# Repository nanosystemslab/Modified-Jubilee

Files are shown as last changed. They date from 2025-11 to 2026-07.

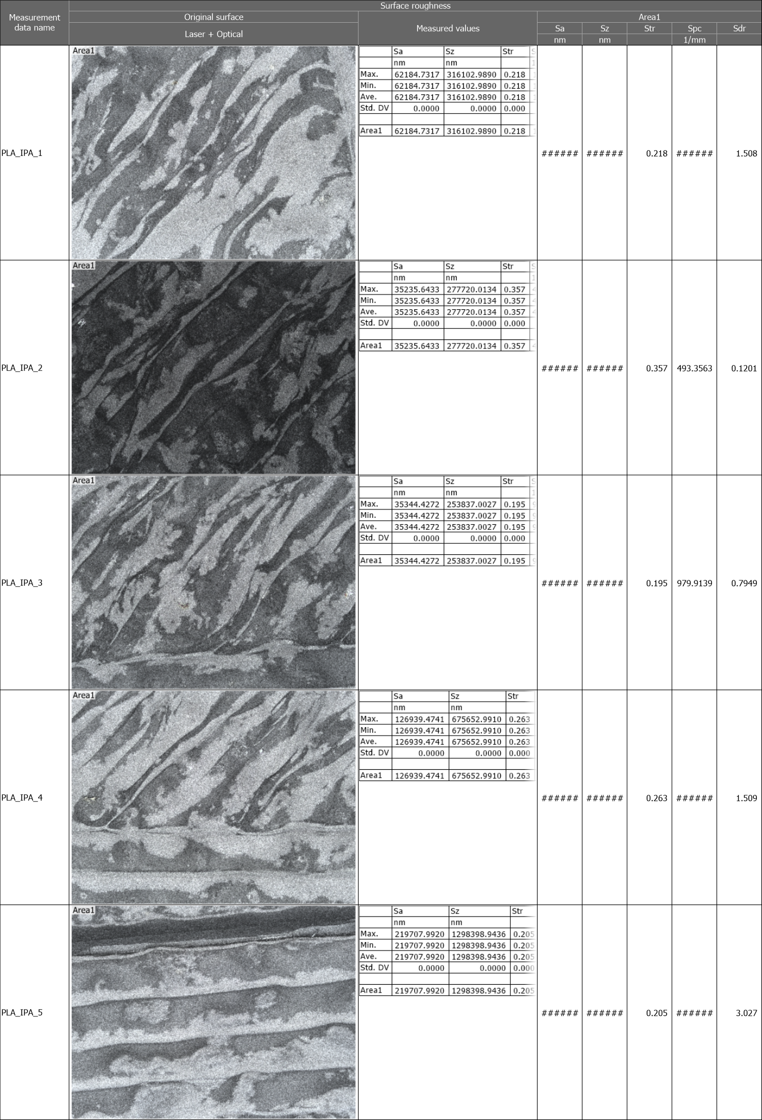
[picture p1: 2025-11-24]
degradation_testing/keyence_analysis/PLA_IPA_Results_Surface roughness.png

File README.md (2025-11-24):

# Modified Jubilee  
### Master’s Thesis Design Files & Documentation  

---

## Overview

This repository contains all design files, mechanical models, firmware, scripts, and supporting documentation used in the development of my Master’s thesis:

**“DESIGN, MODIFICATION, AND EVALUATION OF THE JUBILEE  
OPEN-SOURCE MOTION PLATFORM FOR AUTOMATED DIP COATING”**

This repository exists to support replication, modification, and extension of the system in alignment with open-source hardware principles.

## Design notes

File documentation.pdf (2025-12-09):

# Table of Contents

Purchasing Components:
- Purchase Order 1 (10/8/2024):
- Total procurement time: 3 Weeks
- Aluminum 6061 Plates
■ Procurement Time: 2.5 weeks
■ Manufacturing Time: 3 weeks
- Better to spend the extra money to get the plates machined from an external supplier to accelerate the assembly process
- Filastruder:
■ Missing tool changer stepper motor and its corresponding wires
- Tried to get a replacement part, but Filastruder only offers replacements within 2 week of delivery
- Didn’t notice missing component whilst confirming the contents of all the packages
- Realized 6 weeks post delivery once assembling the tool changer component

Resin Printing:
- General Settings:
- Printer: Formlabs 3/3+
- Material(s): Tough 1500, Grey V4
- Print Orientation: 45º angle
- Layer Thickness: 0.1mm
- Removed generated supports from the inside of screw holes
- Post Processing
- Component Cleaning:
■ First manual IPA wash for 15-30 seconds
■ Second manual IPA wash for 15-30 seconds ■ Automatic IPA wash for 15 minutes
- Material: Tough 1500
■ Cure Settings:
- Temperature: 70º C
- Time: 60 minutes
- Material: Grey Resin V4
■ Cure Settings:
- Temperature: 60º C
- Time: 30 minutes
- Problems:
- Material: Tough 1500
■ Print failure while printing back and front feet
- Both prints failed the first time and succeeded the second time with no changes to the form file
- Reason for failure: Unknown. Should compare the slicer settings of the nslab desktop to my laptop settings
- Heat Creep
■ Research heat creep with formlabs or try different resin type
- Possible debris inside of the resin tank
■ Clean thoroughly or replace
- Dirty/Obstructed UV light
■ Clean thoroughly or replace
- Material: Grey Resin V4
■ Heat inserts don’t stay inside of components
■ Brittle material, lead to some components snapping/breaking

Aluminum Top and Bottom Plates:
- General Information:
- Purchased 2 Aluminum Plates 6061: T651, 24 in Overall Lg, 24 in Overall Wd, 0.25 in Thick, Mill, +/-0.012 in
■ Procurement time: 2.5 weeks
- Had the machine shop cut the Aluminum Plates with the water jet
■ Sent .stl cad files
■ Procurement time: 2.5 weeks
- Problems:
- Aluminum Plates after receiving them from the machine shop: ■ Not all holes were cut all the way with the water jet
- Was able to tap out some of the holes that were mostly cut with hammer
- Rest of the holes had to be drilled out
- 1st Attempt: Took it to FabLab, but the drill press was unable to cut through the aluminum likely due to a lack of speed
- 2nd Attempt: Took it to the machine shop to use their drill press, but had issues with alignment and clamping due to the size of the plates
- 3rd Attempt: Clamped the aluminum plates to a table and hand drilled the holes out with the corresponding drill bit size
■ Finished holes are not perfectly aligned with the corresponding components
■ No finish on the aluminum plates
- Took the deburring tool to smooth out the rough edges on the aluminum plates
■ Minor issue: plates are dirty
- Can clean with IPA or acetone
- Top aluminum plate changed the overall height of the Jubilee. The toolhead can crash into the back Z stopper.
■ Solution: Change the home all function to home x first and y second:
1. Open the homex.g file and comment out the following lines:

if !move.axes[1].homed
M291 R"Cannot Home X" P"Y axis must be homed before x to prevent damage to tool. Press OK to home Y or Cancel to abort" S3
M98 P"homey.g"

2. Then open the homeall.g file and switch the order of the homey.g and homex.g. Should look like this:

; Home y, x, z, and Toolchanger Lock axes

M98 P"homeu.g" ; X and Z require U to be homed first in case a tool is currently active M98 P"homex.g"
M98 P"homey.g"
M98 P"homez.g"

CAD Modeling:
- Heat Inserts:
- Create a countersink hole that extends through the entire component, allowing the heat insert to be threaded into the resin using a screw and washer
■ The following measurements are inner and outer diameters (ID and OD) depending on the insert size
- M3:
- ID: 5.4mm, OD: 6.4mm
- M4:
- ID: 5.9mm, OD: 6.9mm
- For parts that can’t have through holes, press fit inserts into component(s) using a vise
- Back/Top Aluminum Plates:
- Design Process:
■ Create a sketch to represent the horizontal aluminum extrusions or “old frame” (top and bottom) and include all of the vertical aluminum extrusions as well as the PLA components that rest on each frame.
- To create sketches of the solid parts, create a plane on the surface of the face being drawn and offset any planes if necessary.
- If a plane was offset to copy a certain detail of the part, after the detail is drawn switch the sketch plane back to its original plane.
■ Create a sketch of the “new frame” that follows the dimensions of the old frame
- Both top and bottom frames widths were extended by ½” (¼” on each side) to allow for side panels to sit flush with the frames
- After the new frame is sketched and extruded, use the previous sketches of the vertical aluminum extrusions and PLA components to create corresponding holes for each component
■ Ensure each hole is a through hole and the correct diameter
■ Determine which of the holes need to be threaded and which don’t
- All holes that align with the vertical aluminum extrusions do not need threads as they will thread directly into the extrusion ■ Add any adjustments necessary for the new frame

- For the top frame, add a slit at the front of the frame to allow for the addition of new tools such as the Opentron Pipette
- Divide the slit into thirds to provide more rigidity to the structure while maintaining mountability
- Behind the slit add through holes (Number of holes and spacing is up to you) for tools that need to be mounted from the bottom
- For the bottom frame, redesign larger feet to cover more surface area and provide more support to compensate for the increased weight
■ Spacers will need to be added to the motors to compensate for the loss in height with the new assembly
- Calculate the difference in height between the original assembly and new assembly by subtracting the thickness of the horizontal aluminum extrusion (20mm) by the thickness of the top plate (¼” = 6.25 mm)
- 20mm − 6. 25mm = 13. 75mm ≈ 14mm spacers
- The height of the feet will also need to increased by 14mm to ensure that the motors are suspended above the surface the Jubilee is on
■ Lastly import other solid parts to ensure all holes are properly aligned with the frames
- Panels:
- Design Modifications:
■ Back Panel (Electronics Panel):
- Remove 13.65mm from the top and bottom of the panel for it to fit within the dimensions of the modified Jubilee
- Disregard screw holes removed as those can’t be used anyways
- Will be mounted using the holes on the side of the panel ■ Can screw into T-slots mounted to the vertical extrusions
■ Side Panels:
- Remove 20mm from the top and bottom of both side panels (40mm total removed) for it to fit within the dimensions of the modified Jubilee
- Disregard screw holes removed as those can’t be used anyways
- Will be mounted using the holes on the side of the panel

■ Can screw into T-slots mounted to the vertical extrusions
- Automation Deck:
- General Information:
■ Purpose: Modular frame to hold different beakers, tip racks, sample holders, etc.
■ Material: PLA
■ Size: 305mm x 305mm
- Design Process:
■ Create a sketch of the build plate using the original magnetic plate as a layout for the automation deck design to get accurate dimensions
■ Extrude the sketch 6.35 mm (¼ in) to create the automation deck part
■ Sketch 4 equal squares (137.5 mm x 137.5 mm) on the automation deck with 10 mm of spacing between each square
■ Design dovetail connections on the edges of each square to create modular insertions
■ Extrude remove the 4 squares + dovetail connections for the automation deck holders to be inserted
■ Divide design into 4 parts with connectors to fit inside of Bambu X1E build volume
- Automation Deck Holders:
- Design process:
■ Create a sketch using one of the modular holes from the automation deck as a layout to get accurate dimensions
■ Offset the sketch inwards by 0.1 mm
- This is to ensure that the holder can slide into place without force, but still provide a snug fit
■ Extrude the sketch 6.35 mm (¼ in) to match the height of the automation deck
■ Sketch the dimensions of the object (tip rack, vial holder, wellplate, beaker, etc.) on the center surface of the holder
■ Extrude remove the sketch 4.35 mm
- Leave 2 mm of space between your object and the magnetic build plate to keep the two from making direct contact
- Automation Deck Holder - Sample Holder:
- Dry Sample Holder Design Process:
■ Sketch a rectangle that measures 85.5 mm x 127.75 mm ■ Extrude the rectangle 60 mm

■ Create the sample slots:
- Create a construction line 22.5 mm away one of the 127.75 mm sides of the rectangular prism
- Sketch a center point rectangle on the construction line that measures 27 mm x 3 mm
- Create a 2 mm outward offset on this rectangle
- Dimension the 2 rectangles to be 5 mm from one of the 85.5 mm sides of the prism
- Create a linear pattern of the rectangles along the surface of the prism
- This patter should be 10x in the vertical direction and 2x in the horizontal direction
- Spacing between the patterns should be 12.306 mm
■ Extrude remove the slots 53.65 mm
■ Add 5 mm fillets to the corners of the base
■ On the surfaces of the front slots, sketch a center point rectangle that measures 53.65 mm x 23 mm
■ Extrude remove all the way through the object
■ Finally, face blend the base of each slot with a radius of 2.5 mm
- Wet Sample Holder Design Process
■ Design process is the exact same as the dry sample holder, but the dimensions are slightly larger
- These slots will be slightly bigger to allow for more space between the sample and the holder
■ Sketch a rectangle that measures 85.5 mm x 127.75 mm
■ Extrude the rectangle 60 mm
■ Create the sample slots:
- Create a construction line 22.5 mm away one of the 127.75 mm sides of the rectangular prism
- Sketch a center point rectangle on the construction line that measures 29 mm x 5 mm
- Create a 2 mm outward offset on this rectangle
- Dimension the 2 rectangles to be 4 mm from one of the 85.5 mm sides of the prism
- Create a linear pattern of the rectangles along the surface of the prism
- This patter should be 10x in the vertical direction and 2x in the horizontal direction
- Spacing between the patterns should be 12.306 mm
■ Extrude remove the slots 53.65 mm

■ Add 5 mm fillets to the corners of the base
■ On the surfaces of the front slots, sketch a center point rectangle that measures 53.65 mm x 20 mm
■ Extrude remove all the way through the object
■ Finally, face blend the base of each slot with a radius of 1.65 mm
- Vacuum Tool:
- Design Process:
■ Start by sketching a circle with a 14 mm diameter
- This will be the part that contacts the sample
■ Extrude the circle 5 mm
■ On the surface of the cylinder, sketch 2 circles from the centerpoint. ID: 5.12 mm, OD: 7.12 mm
■ Then sketch a path perpendicular to the surface of the cylinder with a height of 20 mm and a length of 25 mm
■ Sweep the face of the circles sketched on the surface of the cylinder using the perpendicular line as the path of the sweep
■ Add a 5 mm radius fillet to the circle at the base of the sweep
- This should create a sturdy connection between the original cylinder and sweep
■ On the bottom surface of the cylinder, sketch a 12 mm diameter circle ■ Extrude remove the 12 mm circle by 5 mm
■ Fillet the inner base of the sweep 5 mm
■ On the bottom surface of the cylinder, create a vacuum chuck design.
- Sketch a 12 mm circle
- Offset sketch a circle from the 12 mm circle by 2 mm
- Offset sketch a circle from the 10 mm circle by 1.2 mm
- Repeat this pattern of offsets (offset by 2 mm, then 1.2 mm) until you can't anymore.
- Sketch 2 perpendicular rectangles along the horizontal and vertical centers of the base of the cylinder
- Extrude remove the 1.2 mm spacings 5 mm to finish chuck design ■ At the opposite end of the model (opening of the sweep), create a sketch perpendicular to the drawing to make the hose barb.
- Sketch 5 mm up from the center of the sweep
- Sketch a 5 mm line away from the surface
- Sketch a 1.3 mm line down
- Sketch a 2 mm line away from the surface
- Sketch a 0.8 mm line up and then a diagonal line 60 degrees from the vertical line.

- The length of the diagonal line should be 1.6 mm
- Copy and paste the barb 7 time to create 8 total barbs
- Close the drawing then revolve the sketch
- Fillet the base of the sweep and the hose barb 2 mm
■ Offset a plane from the center of the 25 mm length of the sweep
■ Create a sketch on that plane and make a rectangle that measures 33.45 mm x 10.45 mm
- Add 2 points 2.725 mm away from the center of the short walls ■ Extrude the sketch 7 mm to connect it to the vacuum tool
■ Add 2 mm fillets between the extruded rectangle and the vacuum tool ■ Finally, create 3.4 mm through holes using the points created in the rectangle sketch

Jubilee Assembly:
- Problems:
- L shaped vertical aluminum extrusions don’t have long enough threads. ■ Solution:
- Buy shorter M5 screws to fit within the thread length
- Holes on the aluminum bottom plates aren’t perfectly aligned with the corresponding components
■ Solution:
- Redrill the holes (Only works for the components that require through holes and not threaded holes)
- Tool wires are heavy and are not well suited for traveling over the top of the Jubilee
■ Solution:
- Reroute the wires

Degradation Testing:
- Keyence Analysis:
- General:
■ 5x Lens
■ Stitched 5 images of the center of the dogbone
- Testing Procedure:
1. Specimen fabrication
a. Design and 3D print 40 ASTM D638 Type V dogbone specimens, consisting of 20 PLA and 20 Grey Resin V4 samples.
2. Solvent exposure
a. Submerge five dogbones of each material in water, isopropyl alcohol (IPA), and acetone for 24 hours.
b. Retain five additional dogbones of each material as unexposed control specimens.
3. Post-immersion inspection
a. After submersion, visually inspect each specimen using a Keyence confocal laser scanning microscope.
b. Acquire and stitch approximately five image scans of the mid-gauge section for each dogbone.
4. Mechanical testing
a. Test every specimen using a Shimadzu tensile tester in accordance with ASTM D638 procedures.
b. Export the resulting force–displacement data as a .csv file.
5. Data analysis
a. From the recorded data, calculate tensile strength, tensile strain at break, and Young’s modulus for each specimen.
- Results:
- Water:
■ In comparison to the control samples for both PLA and Grey Resin V4, the dog bones submerged in water after visual inspection showed no significant differences in appearance.
- IPA:
■ In comparison to the control samples for Grey Resin V4, the dog bones submerged in IPA after visual inspection showed no significant differences in appearance.
■ In comparison to the control samples for PLA, the dog bones submerged in IPA after visual inspection showed extreme disfigurement.
- Acetone:

■ In comparison to the control samples for both PLA and Grey Resin V4, the dog bones submerged in acetone after visual inspection showed no significant differences in appearance.
- Tensile Testing (ASTM D638 Type V):
- General Information:
https://www.ssi.shimadzu.com/products/materials-testing/uni-ttm-system/tensile-test-methods-for-plastics-astm-d638/spec.html (https://www.ssi.shimadzu.com/products/materials-testing/uni-ttm-system/tensile-test-methods-for-plastics-astm-d638/spec.html)

https://www.astm.org/d0638-22.html

https://eddieliberato.github.io/blog/2020-05-14-dogbones/
■ Dogbone specimen dimensions (ASTM D638 Type V):
- Overall length: 63.5 mm
- Gauge length: 7.62 mm
- Width of narrow section (gauge width): 3.18 mm
- Length of narrow section: 9.53 mm
- Distance between grips (overall length of reduced section + grip sections): 25.4 mm
- Width of ends (grip section): 9.53 mm
- Thickness: 3.2 mm (nominal)
- Radius of fillet (transition between narrow and grip sections): 14 mm
■ PLA Print Settings:
- Printer: Bambu Lab P1S
- AMS Attachment
- Filament Type: White PLA Basic
- 0.4mm nozzle
- No supports
- 0.2mm layer height
- 6 perimeter layers (This is especially critical for parts that have heat-set inserts)
- 20% infill * printable in the provided orientations
- outer perimeter layer first
- uncheck "Detect Thin Walls" if your Slicer has this setting.
- Otherwise, small gaps will not be filled.
■ Grey Resin V4 Print Settings:
- Printer: Formlabs 3/3+
- Print Orientation: 45º angle
- Layer Thickness: 0.1mm
- Cure Settings:

- Temperature: 60º C
- Time: 30 minutes
- Data analysis script description:
1. Mount Google Drive and define the data folder.
a. Connects to Google Drive (drive.mount) and sets a folder path containing tensile-test CSV files.
2. Locate all CSV data files.
a. Scans the selected folder and lists every .csv file to be analyzed.
3. Define sample geometry (ASTM D638 Type V).
a. Sets:
i. Gauge length = 7.62 mm
ii. | Width = 3.18 mm
iii. | Thickness = 4 mm
iv. | Cross-sectional area A = width × thickness (mm²)
4. Loop through each CSV file.
a. For every sample:
i. Load the file as a DataFrame with columns Time (s), Force
| (N), and Stroke (mm).
ii. | Remove commas or stray characters and convert text to
| numeric values.
iii. | Drop any rows containing invalid or missing data.
5. Compute stress and strain.
a. Stress (MPa) = Force (N) ÷ Area (mm²)
b. Strain = Stroke (mm) ÷ Gauge length (mm)
6. Estimate Young’s modulus.
a. Select the linear elastic region where strain ≤ 0.002.
b. Perform a linear regression of stress vs. strain.
c. The slope of the fitted line gives Young’s modulus (MPa).
7. Determine tensile strength and elongation.
a. Tensile strength: maximum stress value.
b. Tensile strain: strain corresponding to that maximum stress.
8. Store all calculated results.
a. Saves the computed tensile strength, tensile strain, and Young’s modulus for each sample into a results list.
9. Create a summary table.
a. Converts results into a single DataFrame and adds an “Average” row showing mean values for all samples.
10. Display the summary.
a. Prints a formatted summary table listing all sample files with their corresponding calculated properties and overall averages.

11. Export results to Excel.
a. Writes the summary DataFrame to batch_summary.xlsx in the same Drive folder for record-keeping.
- Future Improvements
- Test multiple different resins ■ Issue:
- Grey Resin V4 is very brittle and not ideal for lots components ■ Solution:
- Test another Formlabs resin such as Tough 1500 which is more flexible than Grey
- Isolate dogbone samples after printing ■ Issue:
- Material properties of the samples will change depending on the environment it is left in causing variations in Tensile Data
■ Solution:
- Place dogbones in a dry box to prevent environmental effects

Vibration Testing:

### 1. Standalone Vibration Data Logger

a. Components:
i. Adafruit MPU-6050 6-DoF Accel and Gyro Sensor - STEMMA QT Qwii (https://www.adafruit.com/product/3886)
ii. | Raspberry Pi Pico WH - Pico Wireless with Headers Soldered (https://www.adafruit.com/product/5544)
iii. | Adafruit PCA9548 8-Channel STEMMA QT / Qwiic I2C Multiplexer -
| TCA9548A Compatible (https://www.adafruit.com/product/5626)
iv. | STEMMA QT / Qwiic JST SH 4-Pin Cable (https://www.adafruit.com/product/4399)
v. Bread Board
vi. | Jumper wires
vii. | 3D printed MPU-6050 holders
b. Testing locations:
i. Tool changer
ii. | Bed
iii. | Frame
Testing procedure:
1. Hardware setup
a. Connect the Raspberry Pi Pico WH and one Adafruit MPU-6050 accelerometer on a breadboard using jumper wires.
b. Connect the I²C multiplexer to the MPU-6050 via a JST 4-pin cable.
2. Sensor mounting
a. Mount the Raspberry Pi + MPU-6050 breadboard assembly onto the magnetic build plate.
b. Mount the other two MPU-6050 sensors to the tool head and the aluminum vertical extrusion, respectively.
3. Electrical connections
a. Connect all mounted MPU-6050 boards to the multiplexer using JST connector cables.
b. Power the Raspberry Pi Pico WH through the micro-USB connector attached to a computer.
4. Software setup
a. Upload the triple_accel.py data-acquisition script to the Raspberry Pi using Thonny.
b. Upload the X-, Y-, and Z-axis simulation scripts to VS Code on the host computer.
5. Data acquisition
a. Run the triple_accel.py script on the Raspberry Pi.
b. After the initial sensor calibration completes, start the corresponding axis simulation script in VS Code.
6. Test completion a. When the VS Code terminal indicates that the simulation has finished, stop the triple_accel.py script to end data collection.
7. Data handling and analysis
a. Download the generated .csv data file from the Raspberry Pi.
b. Process the file using the vibration-analysis Python script to generate FFT and time-domain plots.
8. Repetition
a. Repeat the complete procedure for each axis (X, Y, Z) on both the modified and original Jubilee platforms.

Data collection script description:
1. Pick an I²C bus that actually works.
a. Tries a few common Pico pin combos and selects the first config that returns any devices on a scan.
2. Probe what’s on the bus.
a. Scans for a PCA9548A I²C multiplexer and for any directly connected MPU6050 (0x68).
3. If a PCA is present, sanity-check its channels.
a. Selects channels (0–7), scans each for an MPU6050 at 0x68, records which channels really have sensors, then disables all channels.
4. Instantiate sensor objects.
a. Adds a direct MPU6050 if one is found on the main bus.
b. Adds PCA-routed MPU6050s for the channels that tested positive (e.g., Ch0, Ch1).
5. (Optional) Calibrate all sensors.
a. If enabled, asks you to leave the rig still, averages a bunch of samples per sensor, and sets offsets so X≈0 g, Y≈0 g, Z≈+1 g when level.
6. Let everything settle.
a. Waits a few seconds (warm-up), then repeatedly tests stability: collects short bursts from each sensor and checks that the standard deviation of X, Y, Z, and |accel| is below a small threshold. Retries up to a fixed limit.
7. Choose the run mode: live or log.
a. Live mode: continuously prints each sensor’s X, Y, Z, and acceleration magnitude at the target sample rate.
b. Logging mode: writes rows to a CSV file at the target sample rate for the specified duration (or until you stop it).
8. Sample loop (both modes).
a. On each tick: read all sensors, compute magnitude, mark any failed read as NaN, and keep time with millisecond ticks.
9. Progress feedback.

a. Once per second, prints a status line with elapsed time, total samples, and whether any read errors occurred.
10. Clean finish.
a. On duration end (or Ctrl+C), stops the loop; in logging mode it closes the file and reports how many samples and sensors were captured.
11. Core assumptions & constants baked in.
a. MPU6050 is at ±2 g scale (divides raw by 16384).
b. Default addresses: PCA = 0x70, MPU6050 = 0x68.
c. Defaults include sample rate (e.g., 500 Hz), settling window, stability threshold, and which PCA channels to try.

X-axis movement script description:
1. Initialize the controller.
a. The script starts by defining the Jubilee’s IP address and creating an HTTP session to communicate with the Duet 3 web control interface.
2. Set movement parameters and limits.
a. It defines safe X-axis limits (e.g., −3 mm to 303 mm) and a default travel speed (e.g., 3000 mm/min).
3. Send G-code commands through HTTP.
a. Commands like G1 X... F... are sent to the printer’s /rr_gcode endpoint to move the tool head, and responses are read back as JSON.
4. Check current position.
a. The code queries /rr_status to get the current X coordinate and uses it as the reference “starting position.”
5. Run a defined number of back-and-forth cycles (default = 3).
a. For each cycle:
i. Move the tool head to the minimum X position.
ii. | Wait until motion completes and optionally pause for a few seconds.
iii. | Move the tool head to the maximum X position.
iv. | Wait again and pause.
v. Log progress and repeat until all cycles are done.
6. Wait for motion to finish before continuing.
a. Uses M400 and periodic status checks to confirm the machine is idle before proceeding to the next move.
7. Pause at end points for sensor stability.
a. Short pauses (e.g., 5–10 s) give time for accelerometer data collection or vibration settling before direction changes.
8. Return to the starting position.
a. After completing all cycles, the script moves the X-axis back to the original position where the test began.

9. Handle errors gracefully.
a. If anything fails (connection loss, timeout, etc.), it logs the error and tries to return the tool head to the starting position.
10. Provide detailed logging output.
a. Throughout the run, timestamps and messages are written to the console describing every movement, pause, or error condition.

Y-axis movement script description:
1. Connect to the Jubilee printer.
a. The script begins by creating an HTTP connection to the Duet 3 controller using the printer’s IP address.
2. Define motion limits and speed.
a. Safe travel bounds for the Y-axis (e.g., −34 mm → 280 mm or 295 mm) and a default feed rate (≈ 3000 mm/min) are set.
3. Send motion commands via HTTP.
a. G-code commands such as G1 Y### F### are sent to the /rr_gcode endpoint to move the toolhead along the Y-axis.
4. Read current position.
a. The script queries /rr_status to determine the current Y coordinate, which is saved as the “starting position.”
5. Run a multi-cycle travel routine.
a. The head moves from minimum → maximum → minimum Y positions for a set number of cycles (default = 3).
6. Pause at each extreme.
a. After reaching each limit, the machine waits several seconds (e.g., 5–10 s) to allow for vibration settling or acceleration-sensor sampling.
7. Wait until motion completes.
a. The script issues an M400 command and repeatedly checks printer status to confirm the move has fully finished before continuing.
8. Repeat the pattern.
a. Each back-and-forth motion counts as one cycle; short pauses occur between cycles to ensure consistent timing.
9. Return to the start position.
a. Once all cycles finish, the head moves back to its original Y location and confirms completion.
10. Handle errors safely.
a. If communication or motion fails, the script logs the problem and attempts to return the toolhead to its starting point before exiting.
11. Log progress to the console.
a. Every major action—move, pause, completion, or error—is time-stamped and printed for test documentation.

Z-axis movement script description:
1. Connect to the Jubilee’s controller.
a. The script starts by creating an HTTP session to communicate with the Duet 3 web control interface using the Jubilee’s IP address.
2. Define safe motion parameters.
a. It sets a safe vertical travel range (e.g., 10 mm → 290 mm) and a conservative default speed (around 2000 mm/min) since the Z-axis moves the entire tool head assembly.
3. Send G-code commands over HTTP.
a. Commands such as G1 Z### F### are sent to move the tool head up or down, and /rr_gcode responses confirm successful communication.
4. Determine the starting Z position.
a. The script queries the printer’s /rr_status endpoint to read the current Z coordinate, storing it to return to later.
5. Run a three-cycle motion routine.
a. For each of the three cycles:
i. Move down to the minimum Z limit (closest to the bed, but safely above it).
ii. | Wait until motion finishes and pause for a few seconds.
iii. | Move up to the maximum Z limit (near the top of travel).
iv. | Wait again and pause.
v. Record progress and continue.
6. Confirm each motion is complete.
a. The script issues M400 (wait for moves to finish) and periodically checks machine status until it reports idle.
7. Include controlled pauses.
a. Short dwell times at each endpoint allow vibration damping or sensor data capture before the next move.
8. Repeat until all cycles finish.
a. Each up-and-down motion pair counts as one cycle; after three cycles the sequence stops.
9. Return to the starting height.
a. Once the final cycle is complete, the head moves back to its original Z position and confirms motion completion.
10. Handle errors gracefully.
a. If communication or motion fails, the script logs the issue and tries to safely return the tool head to its start position.
11. Provide continuous console feedback.

a. Every move, pause, and status check is timestamped and printed through the logger, giving a clear record of the full test.

Data analysis script description:
1. Configuration and Sensor Mapping:
a. Each script defines a fixed sampling rate of 100 Hz.
b. Accelerations are provided in units of g and converted to m/s² using a constant multiplier.
c. Displacement calculations convert meters to millimeters.
d. Sensor names are mapped to physical locations on the system:
i. MPU_Direct → bed plate
ii. | MPU_Ch0 → vertical extrusion
iii. | MPU_Ch1 → tool head
c. Each sensor location is assigned a distinct color for all plots.
d. The scripts specify:
i. Path to the folder containing CSV files
ii. Output directory for figures and summary spreadsheets
2. Input Data and Column Requirements:
a. All CSV files must contain consistently named columns for each sensor.
b. The FFT analysis script expects magnitude columns for each sensor, such as:
i. MPU_Direct_mag
ii. | MPU_Ch0_mag
iii. | MPU_Ch1_mag
c. The displacement analysis script expects x, y, and z acceleration component columns for each sensor.
d. The displacement script requires a timestamp column in seconds.
e. The scripts assume the sampling rate and do not estimate it from the data.
3. Frequency-Domain Analysis (FFT Script)
a. Each CSV file is processed sequentially.
b. For each sensor:
i. The acceleration magnitude is read from the corresponding column.
ii. | Values are converted from g to m/s².
iii. | The mean is removed to eliminate DC offset.
iv. | A Hanning window is applied to reduce spectral leakage.
v. A Fast Fourier Transform (FFT) is performed using a one-sided spectrum.
vi. | Frequency bins are generated based on the sampling rate and number of
| samples.
vii. | FFT magnitudes are normalized properly for comparison.
c. Peaks are automatically identified:
i. Frequencies below 1 Hz are ignored.

ii. | Peak detection uses a prominence threshold based on data amplitude.
iii. | The top three peaks are extracted, sorted, and reported.
d. FFT figures include:
i. Frequency range from 0 to 50 Hz
ii. | Clean spectrum lines for all sensors
iii. | Markers at each dominant peak
iv. | Sensor labels, legend, and grid lines
e. Each figure is saved as a PNG file with a filename indicating the source CSV.
f. Numerical results printed for each file include:
i. Sampling rate and Nyquist frequency
ii. | Frequency resolution
iii. | Three dominant vibration frequencies for each sensor
iv. | Corresponding magnitudes
4. FFT Summary Outputs for Multiple Files
a. When more than one CSV file is present, the script generates:
i. A summary comparison figure showing peak frequencies and magnitudes
| across all files and sensors
ii. | An Excel spreadsheet containing:
1. Peak frequencies and magnitudes for each file and sensor
2. Pivot tables comparing the dominant peak across all tests
5. Time-Domain Displacement Analysis (Displacement Script)
a. Each CSV file is processed sequentially using x, y, and z accelerations.
b. For each sensor and each axis:
i. Acceleration is converted from g to m/s².
ii. | The mean is removed.
iii. | A fourth-order Butterworth band-pass filter is applied:
1. Passband: 5–40 Hz
iv. The filtered acceleration is integrated numerically to obtain velocity.
v. Velocity is detrended to remove drift.
vi. | Velocity is integrated again to obtain displacement.
vii. | Displacement is detrended to remove offset and low-frequency drift.
c. The displacement magnitude is computed from the x, y, and z components and converted to millimeters.
d. For each sensor:
i. RMS displacement is calculated.
ii. Peak displacement and the time of occurrence are determined.
e. Each displacement-versus-time figure includes:
i. Traces for all sensors
ii. | RMS displacement in the legend
iii. | A marker and label at the maximum displacement point

iv. Axes labels, legend, and grid
f. Each figure is saved as a PNG file using the source CSV filename.
6. Displacement Summary Outputs for Multiple Files
a. When multiple CSV files are processed, the script generates:
i. A comparison plot showing RMS displacement for each sensor across all
| tests
ii. | A comparison plot showing peak displacement for each sensor across all
| tests
iii. | An Excel summary file containing:
1. RMS displacement for each file and sensor
2. Peak displacement for each file and sensor
3. Time of maximum displacement
4. Pivot tables for cross-file comparisons
7. Batch Processing and Running the Scripts
a. Both scripts automatically scan the data folder and process every CSV file found.
b. The user only needs to:
i. Specify the data folder path
ii. | Specify the output folder path
iii. | Run the FFT script to generate all frequency-domain analyses
iv. | Run the displacement script to generate all time-domain analyses
c. Each script produces:
i. Individual plots per CSV file
ii. | Printed numerical summaries
iii. | Summary comparison plots (if multiple files exist)
iv. | Excel spreadsheets with structured analysis results
- Future Improvements
- Start data collection and axis movement simultaneously
| ■ Issue:
| ● Need to use 2 different programs to communicate with the
| Raspberry Pi and the Jubilee
| ■ Solution:
| ● Run both scripts on one program
- Isolate the testing environment
| ■ Issue:
| ● Jubilee is susceptible to many environmental properties which may
| cause unwanted fluctuations in the data collection
| ■ Solution:
| ● Find a more isolated location to conduct testing

Color Mixing Demonstration:
- Components:
- 350ul wellplate
- Opentron pipette tip rack
- 3 scintillation vials
- Red, yellow, and blue food coloring
- OT-2 P300 pipette
- Raspberry Pi High Quality HQ Camera - 12MP (https://www.adafruit.com/product/4561)
■ 16mm 10MP Telephoto Lens for Raspberry Pi HQ Camera - 10MP (https://www.adafruit.com/product/4562)
■ Arducam CSI to USB UVC Camera Adapter Board for Raspberry Pi HQ Camera, 12.3MP IMX477 Camera Board (https://www.amazon.com/gp/product/B08NVG2CY4)
- 3D printed holders
- Testing procedure:
1. Tool preparation
a. 3D print and install all tool holders and tools on the Jubilee platform.
2. Solution preparation
a. Prepare and mix red, yellow, and blue food coloring solutions, and dispense them into the scintillation vials.
3. Automation deck configuration
a. Define all deck locations in the deck_grid.json configuration file to match the physical layout of vials, tip racks, and the 96-well plate.
4. Software setup
a. Upload the run_color_mixing_demo.py script to VS Code.
5. Dry run validation
a. Perform a dry test (without liquids) to verify that all deck coordinates are correct and that the machine operates as intended.
6. Automated color mixing
a. Execute the color mixing demo to carry out the fully automated pipetting and mixing sequence.
- Simulation script description:
1. Import all modules and setup environment.
a. Loads libraries for CSV logging, OpenCV imaging, NumPy math, and the Jubilee control modules for motion, pipetting, and deck layout (vials, plate, tips).
2. Define machine and user parameters.
a. Sets IP address, camera specs, vial/tip/well positions, pipette volume calibrations, approach distances, Z-axis speeds, and travel speeds for automation.
3. Specify batch design.
a. Defines how many samples to make and what color ratios or explicit per-color volumes to use (e.g., 50 % R, 30 % Y, 20 % B for 272 µL total).
4. Initialize helper and movement functions.
a. Provides small utilities to:
i. Send raw G-code (_gcode)
ii. | Pause for dwell times
iii. | Move above vials, wells, or tips
iv. | Execute approach → pause → dive motions
v. Handle single-press tip pickup and V-axis eject sequences
5. Setup liquid-handling routines.
a. Implements low-level steps for:
i. Aspirating from vials using the V-axis to draw liquid up
ii. | Dispensing into wells and performing a blowout
iii. | Mixing within wells by repeated aspirate/dispense cycles with full
| volume
6. Define camera functions.
a. Handles capturing one frame from the connected camera, computing a circular-mask mean RGB value at the image center, and saving images as JPEGs.
7. Compute per-sample color volumes.
a. For each sample, resolves exact red, yellow, and blue microliter values, using either the per-sample explicit volumes, a global override, or default ratios.
8. Run the main batch loop.
Initializes the pipette, selects the correct tool, and iterates through target wells:
a. For each sample:
i. Pick up and use one dedicated tip for each color (R, Y, B).
ii. | Aspirate from each color’s vial and dispense into the destination
| well.
iii. | Return each tip to its slot.
iv. | Pick up a fourth “mixing” tip and run mixing cycles to homogenize
| the color.
9. Capture and analyze the result.
a. Switch to the camera tool and move above the mixed well.
b. Capture an image and compute mean RGB values (either through OpenCV or the optional image-processing module).
c. Save the photo and measured RGB values for documentation.
10. Log experiment data to CSV.
a. Appends a line to color_mixing_log.csv with timestamp, well ID, color volumes, RGB means, camera info, and which tip positions were used.
11. Repeat for all samples.

a. Automatically moves to the next well and repeats pickup, mixing, imaging, and logging until the full batch is complete.

Automated Dip Coating:
- Components:
- Coating solution: spray paint
- 300ml beaker
- 25 x 75 x 1mm microscope slides
- 3D printed holders
- Rocker 300 Vacuum pump
- US Solid Motorized Ball Valve
- Vacuum tubing
- Keyence Analysis:
- General:
■ 20x lens
- Testing procedure:
1. Tool preparation
a. 3D print and install all tool holders and tools on the Jubilee motion platform.
b. Vacuum setup:
i. Plug in and place the Rocker 300 vacuum pump
1. Ensure the pump is on a stable surface with enough ventilation.
2. Keep the inlet hose barb accessible.
ii. Connect the vacuum tubing from the pump to the manifold
1. Attach the tubing securely to the manifold inlet. iii. Connect tubing from the manifold to the vacuum tool and US Solid Motorized Ball Valve
1. Confirm airtight connections on all ports.
2. Use clamps if needed to prevent leaks.
iv. Mount the motorized ball valve to the Jubilee frame using a 3D-printed bracket
1. Ensure the mount supports the weight of the valve and
| prevents strain on tubing.
2. Route cables safely away from moving axes.
2. Solution preparation
a. Prepare a beaker containing the coating solution and place it on the automation deck.
3. Automation deck configuration
a. Define all deck locations in the deck_grid_dip.json configuration file to match the physical positions of the dry tray, wet tray, and coating bath.
4. Software setup
a. Upload the run_dip_coating_demo.py script to VS Code.

5. Dry run validation
a. Perform a dry test (without the coating solution) to confirm that all deck coordinates are correct and that the machine operates as intended.
6. Automated dip coating
a. Execute the automated dip coating routine to coat all designated samples under controlled submersion times and withdrawal speeds.
7. Post-coating analysis
a. Analyze the coated samples using a Keyence confocal laser scanning microscope to visualize and measure film thickness.
8. Data recording and visualization
a. Record the film thickness of each sample and plot film thickness versus withdrawal speed to evaluate coating uniformity and process performance.
- Simulation script description:
1. Import local Jubilee + deck helpers.
a. Loads a JUBILEE controller and deck-grid functions (safe_z, surface_z, z_hover, slides_dry, slides_wet, bath) from local modules.
2. Define user-tunable parameters.
a. Sets XY/Z speeds, all pause durations, dip depth, per-sample submersion times & withdrawal speeds, tray grid size, starting slot, number of samples, tool selection (T1), approach clearances, and a side-pickup Y-offset.
3. Set vacuum valve behavior (inverted logic).
a. vacuum_close() → hold slide (vacuum ON).
b. vacuum_open() → release slide (vacuum OFF).
Both include short delays to let the pneumatic state settle.
4. Provide convenience moves.
a. Helpers move to safe Z, and to XY targets above dry tray, wet tray, and bath, using approach heights and small timing buffers.
5. Implement side-pickup sequence (dry tray).
a. For a given (row, col):
i. Close valve first (pre-vacuum).
ii. | Go to XY at Y-offset behind the slide at safe Z; pause.
iii. | Lower to pickup Z; pause.
iv. | Advance in Y to contact the slide; pause.
v. Keep vacuum closed (holding), then Z-only lift to safe Z.
6. Implement bath dip sequence.
a. Move above bath → pause → approach to bath surface → dive to depth → submerge for the per-sample time → withdraw at per-sample feed → pause → return to safe Z.
7. Implement place sequence (wet tray).

a. Move above target wet slot → descend to approach then placement Z → pause → open valve to release → pause → back to safe Z → final safeguard: ensure valve is open.
8. Iterate tray positions in column-major order.
a. Generator yields (row, col) pairs across the configured grid starting from START_ROW, START_COL, until N samples are processed.
9. Select tool and initialize valve.
a. If enabled, issues T1 and opens valve (release state) before starting the batch.
10. Run the full batch loop.
a. For each sample index and tray slot: pickup → dip → place, using per-sample overrides when provided, else fallbacks.
11. Log each run to CSV.
a. Appends a row to dip_coating_log.csv with timestamp, index, source/destination slots, dip depth, submersion time, and withdrawal speed.
12. Honor built-in safety/time buffers.
a. Frequent safe_z() retreats and short sleep buffers help prevent collisions and let pneumatics settle between actions.
13. Assumptions & prerequisites.
a. Axes are already homed in Duet; deck coordinates and heights come from your local deck_grid_dip configuration; the IP/connection details live inside your local JUBILEE controller.
14. End state.
a. After the last sample is placed and logged, prints a batch complete message.
- Future Improvements
- Redesign automation deck/holders to make it easier for removal
■ Issue:
- The holders fit perfectly flush into the automation deck which makes it difficult for removal without taking out the screws holding the deck to the magnetic build plate
■ Solution(s):
- Make handles on the holders for easy removal
- Redesign automation deck to attach via clips instead of screws
- Sync python script and Duet mini ■ Issue:
- The python script sends commands faster than the Duet can execute them causing the machine to fall behind the script leading to errors.

■ Current work around:
- Add longer pauses after the dipping command is executed
- The problem with this is that it works for slower speeds, but if you are dipping multiple samples with varying speeds the samples with higher dip speeds will just hover until the pause is finished, wasting valuable time.
- Not enough dipping solution for all samples ■ Issue:
- The oil based paint used can not be evenly distributed for consecutive samples
■ Solution:
- Obvious solution is to use a more viscous solution intended for dip coating
- Use scintillation vials with paint inside, switch tools from the vacuum to the pipette, then aspirate/disperse more paint into the dipping beaker
- Vacuum blowing on samples ■ Issue:
- After release the vacuum blows on the samples causing them to rattle and hit the holder potentially ruining the film
■ Solution:
- Redesign the wet sample holder to hold the samples in a slanted orientation rather than vertical
- Reduce the pause time after releasing the sample
- Redesign holders to avoid ruining the film on at least one side of the sample ■ Issue:
- Samples lean on the holder creating contact on the film and lessening the uniformity of the film on the surface of the substrate ■ Solution:
- Redesign holders

Software:
- Useful links for the Duet boards
- Getting connected to your Duet (https://docs.duet3d.com/en/How_to_guides/Getting_connected/Getting_connected_to_your_Duet)
- GCode dictionary (https://docs.duet3d.com/User_manual/Reference/Gcodes)
- Problems:
- The Duet 3 Mini 5+ was unable to communicate with the Duet 3 Expansion Board 3HC. The 3HC board powered on (indicated by a slow-blinking red LED), but all communication attempts such as M122 B1 or M115 B1 resulted in CAN response timeouts. This prevented X and Y motors from being enabled or homed. ■ Troubleshooting steps:
1. Confirmed physical CAN wiring
- Ensured proper connection from Duet 3 Mini 5+ CAN pins to 3HC CAN IN
- Verified CANH → CANH and CANL → CANL
- Swapped CANH/CANL to test for reversed polarity — no change
2. Verified CAN termination
- Checked that only two termination jumpers were present (one on Duet 3 Mini, one on 3HC)
3. Tested with a known-good CAN cable
- Replaced the CAN cable — no change in behavior
4. Monitored 3HC LED behavior
- Observed a slow red blink indicating board was powered but not communicating over CAN
5. Attempted standard address assignment
- Ran commands like M952 B1 A121 to assign a new address — all failed with response timeouts
- Tried setting CAN bus speeds (250k, 500k, 1M) using M952 — still no communication
6. Scanned for unknown assigned addresses
- Sequentially queried possible CAN addresses using M122 B0, M122 B1, … M122 B125
- Success: M122 B121 returned valid diagnostics, confirming the 3HC was already assigned to address 121
7. Confirmed 3HC health
- Valid M122 B121 output showed:
■ Firmware 3.4.1 installed
■ CAN communication healthy (no packet loss or timeouts)
■ Drivers responding with no errors

8. Updated config to use correct address
- Changed all M584, M569, and M574 entries in config.g that referenced 1.x to 121.x
9. Resolved “Failed to enable endstops” error
- Found that M574 lines were still referencing pins on 1.ioX.in
- Updated those to 121.ioX.in to match the actual CAN address of the 3HC
10. Successfully homed all axes
- After fixing the endstop pin mappings and confirming motor driver mappings, all axes were able to home properly using G28
- Underperforming Z motor
■ Troubleshooting steps:
1. Swapped motor cables
- Swapped the motor cables between the problematic Z motor and a known-good motor to verify if the issue follows the cable (cable/motor) or stays with the driver (driver/electrical).
2. Swapped motors
- Installed a known-good stepper motor onto the problematic driver (0.2 on the Duet 3 Mini 5+).
3. Checked and attempted to correct G-code configuration
- Reviewed and attempted to update relevant G-code (config.g, bed.g) to ensure all Z motors are mapped properly.
- Looked for issues in M584, M92, and M350 commands (driver mapping, steps/mm, and microstepping settings).
- Result: Identified the need to ensure independent Z drivers during bed leveling (M584 Z0.2 U0.3 V0.4) and matching step/mm settings (M92 Z400 U400 V400) and microstepping (M350 Z16 U16 V16 I1).
4. Z-axis motors were swapped with the x/y-axis motors
- Loud Idling of the Z and U (tool changer) motors: ■ Troubleshooting steps:
1. Added stealthChop2 G-code command to the config file
- Add D3 to the following lines of code:
■ M569 P0.2 S0 D3
■ M569 P0.3 S0 D3
■ M569 P0.4 S0 D3

■ M569 P0.1 S0 D3
- Z probing would probe in locations off the bed ■ Troubleshooting steps:
1. Rewire the Z motors to ensure that they match the order

Tools:
- Tool Prerequisites:
- Setting tool parking locations:
■ https://science-jubilee.readthedocs.io/en/latest/building/parking_posts.htm l (https://science-jubilee.readthedocs.io/en/latest/building/parking_posts.html)
- Setting tool offsets:
■ https://science-jubilee.readthedocs.io/en/latest/getting_started/new_user_g uide.html#setting-tool-parking-post-positions-and-offsets (https://science-jubilee.readthedocs.io/en/latest/getting_started/new_user_guide.html)
- Top down camera
- Hardware:
■ Issues:
1. Parking post does not align with toolchanger
- Solution:
i. Use original parking post 3d model for Jubilee camera tool
ii. | Increase the height of the model by 3mm (from
| 22mm to 25mm)\
iii. | Move the dowel pin holes up 3mm
- OT-2 Pipette
- Hardware:
■ Issues:
1. Parking post does not align with the toolchanger
- Solution:
i. Use 55mm parking post 3d model
ii. | Move dowel pins holes down 6mm
iii. | Increase distance between dowel pin holes to 57mm
- Electronics:
■ Issues:
1. Miswired the stepper motor connection and fried the memory board on the OT-2 Pipette
- Solution:
i. Remove the plate from the pipette to access the
| electronics
ii. | Unplug and remove the fried memory board (not
| needed for the Jubilee)
iii. | Verify the functionality of the pipette’s internal
| stepper motor and limit switch
iv. | Solder wires directly onto the limit switch and
| stepper motor
- Software:

■ Issues:
1. Unable to define external pipette limit switch as a Z axis endstop
- Solution:
i. Comment out the following line from the original config file:
“M574 Z0”
- Vacuum
- Hardware:
■ Rocker 300 Oil Free Vacuum Pump (https://www.rocker.com.tw/en/product/laboratory-pump-en/oil-free-vacuum-pump-en/rocker-300-oil-free-vacuum-pump/) ■ U.S. Solid Motorized Ball Valve (https://ussolid.com/products/u-s-solid-motorized-ball-valve-1-4-stainless-steel-electrical-ball-valve-with-full-port-9-24-v-ac-dc-2-wire-auto-return-html) ■ Clear vacuum tubing - ID: 10 mm
- Electronics:
■ Issues:
1. Valve requires 12V of power
a. Solution
i. Make a 2 pin connector and plug in to one of the 12V fan ports on the Duet 3 Mini 5+
1. Port out_5
- Setup Procedure:
1. Solder a 2-pin connector to the power leads of the U.S. Solid motorized ball valve. Verify the electrical connection is secure.
2. Place the Rocker 300 vacuum pump and the motorized ball valve next to the Jubilee platform so that both components are easily accessible.
3. Mount the motorized ball valve to the Jubilee frame using the 3D-printed connector piece. Ensure the valve is firmly secured and does not move during operation.
4. Connect the vacuum tubing from the pump outlet to the valve inlet. Use 10 mm inner-diameter (ID) clear tubing. Ensure the connection is airtight.
5. Connect another length of vacuum tubing from the valve outlet to the vacuum pickup assembly on the Jubilee. Confirm all tubing connections are fully seated and leak-free.
6. Plug the 2-pin connector from the motorized valve into the OUT_5 fan port (or any available 12 V fan port) on the Duet 3 Mini 5+ controller. Confirm that this port is configured for 12 V output.
7. In the Jubilee configuration file (config.g), under the device-mapping section, add the following line to map the valve to a fan channel: M950 F1 C"out5" ; Map vacuum valve to output port OUT_5
8. Home the Jubilee to ensure motion control is active.
9. Test the valve operation using the following commands:

To close the valve (enable suction and pick up an object): M106 P1 S0

To open the valve (disable suction and release an object): M106 P1 S1.0

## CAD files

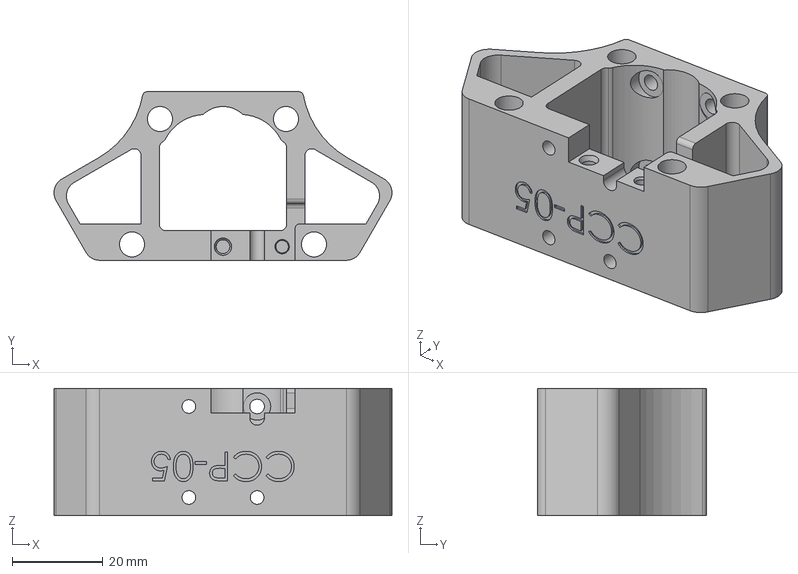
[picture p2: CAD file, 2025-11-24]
cad_models/hardware_modifications/modified_heat_insert_components/m3_heat_inserts/step_files/carriage_center_plate.step
74.3 x 37.1 x 28.0 mm

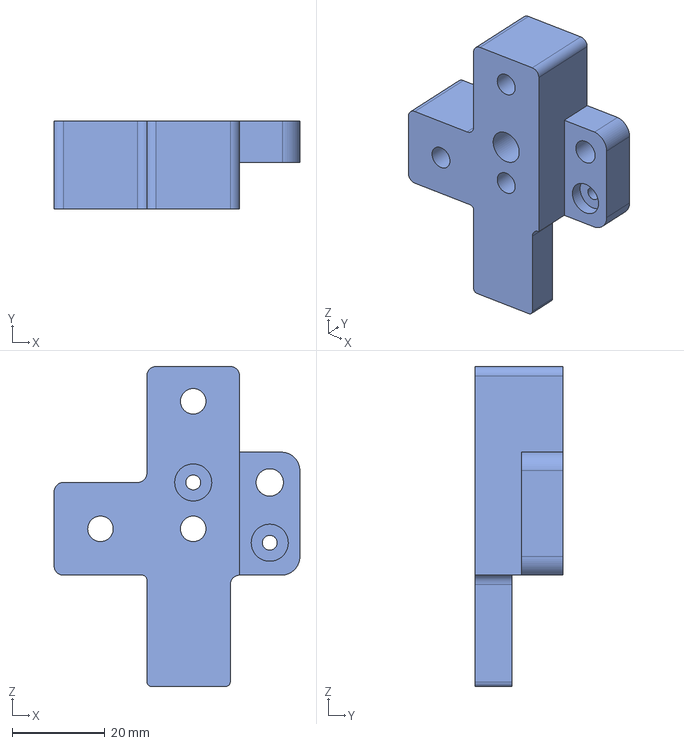
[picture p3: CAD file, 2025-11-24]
cad_models/hardware_modifications/modified_heat_insert_components/m4_heat_inserts/step_files/resin_double_pulley_corner_bracket_right_corner_pulley_plate.step
53.0 x 19.0 x 69.0 mm

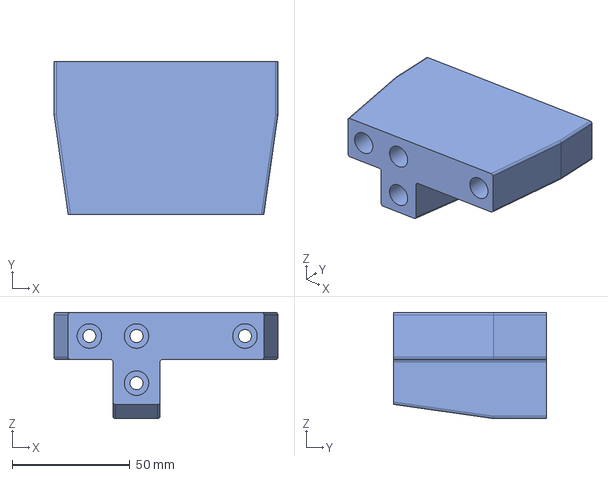
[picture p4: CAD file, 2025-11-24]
cad_models/hardware_modifications/other_modified_components/step_files/back_left_foot.step
95.0 x 65.0 x 45.0 mm

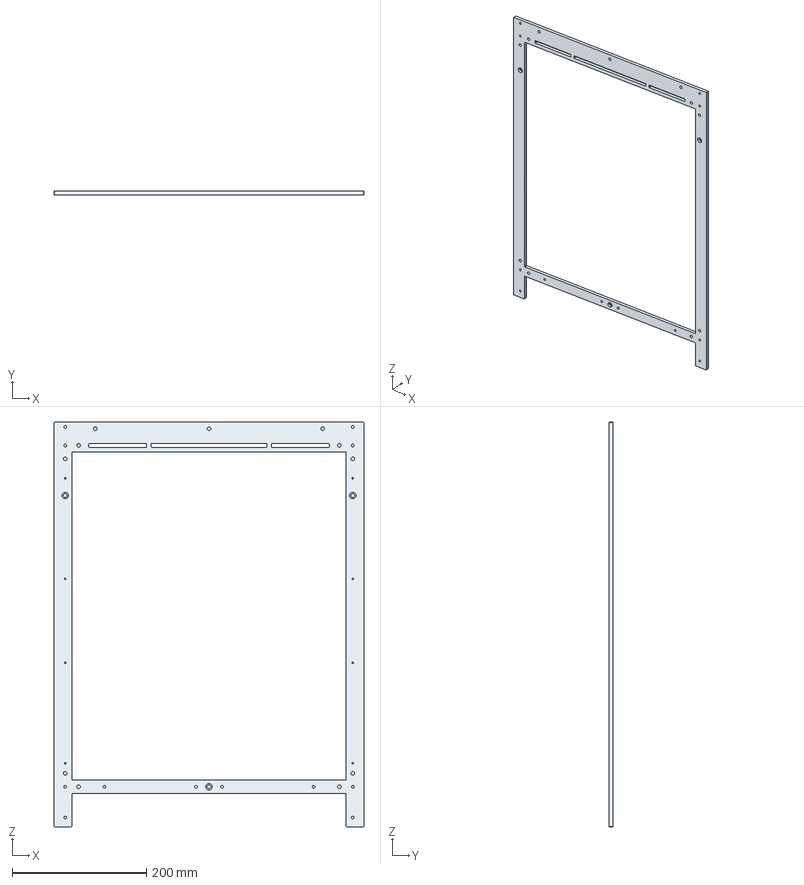
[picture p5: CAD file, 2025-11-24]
cad_models/hardware_modifications/top-bottom_plates/step_files/frame_top_plate.step
461.7 x 6.35 x 604.0 mm

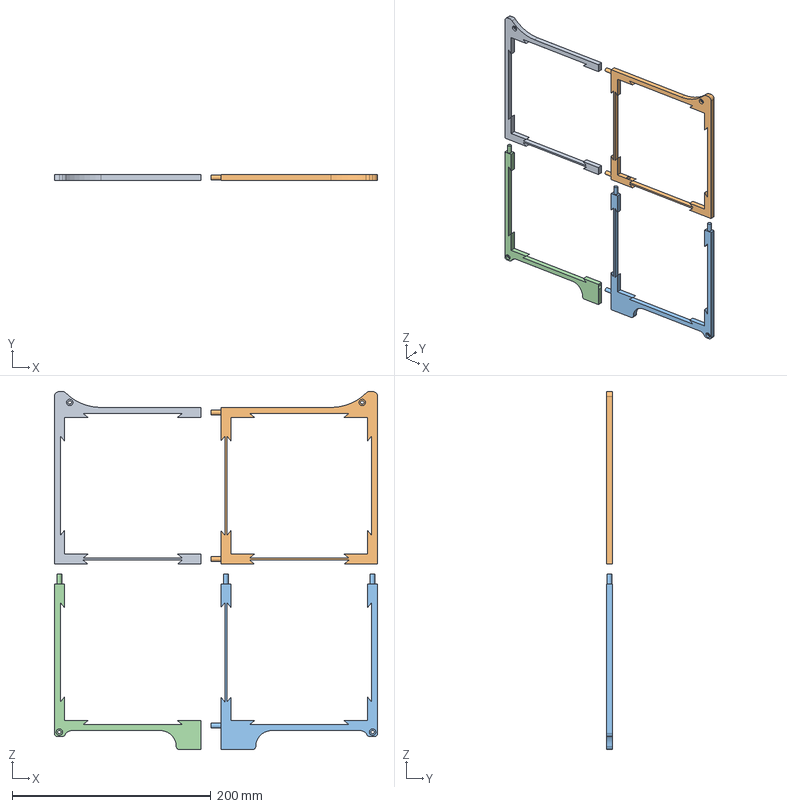
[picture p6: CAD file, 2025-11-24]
cad_models/tools/automation_deck/step_files/automation_deck.step
325.0 x 6.35 x 360.0 mm

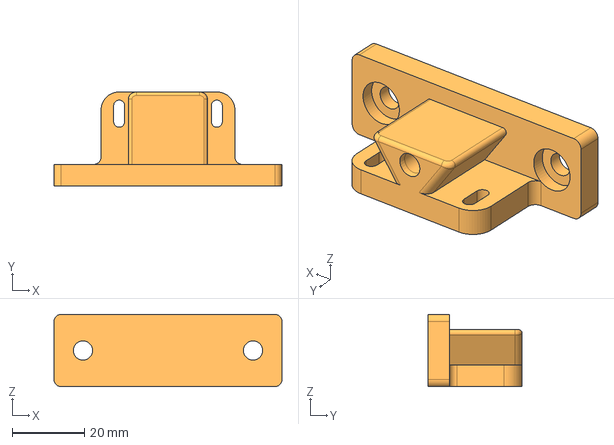
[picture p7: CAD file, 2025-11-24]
cad_models/tools/OT2_pipette/step_files/modified_pipette_parking_post_base.step
63.0 x 26.0 x 20.0 mm

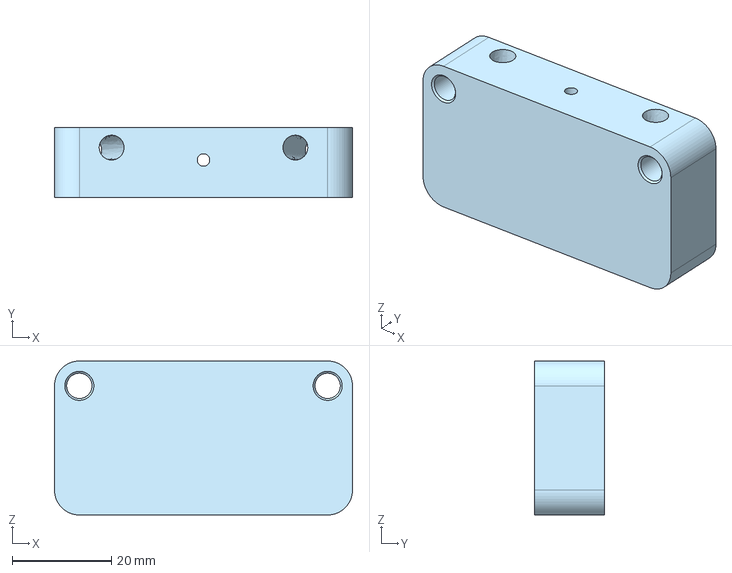
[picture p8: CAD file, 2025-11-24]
cad_models/tools/raspyberry_pi_cam/step_files/modified_camera_tool_holder.step
60.0 x 14.0 x 31.0 mm

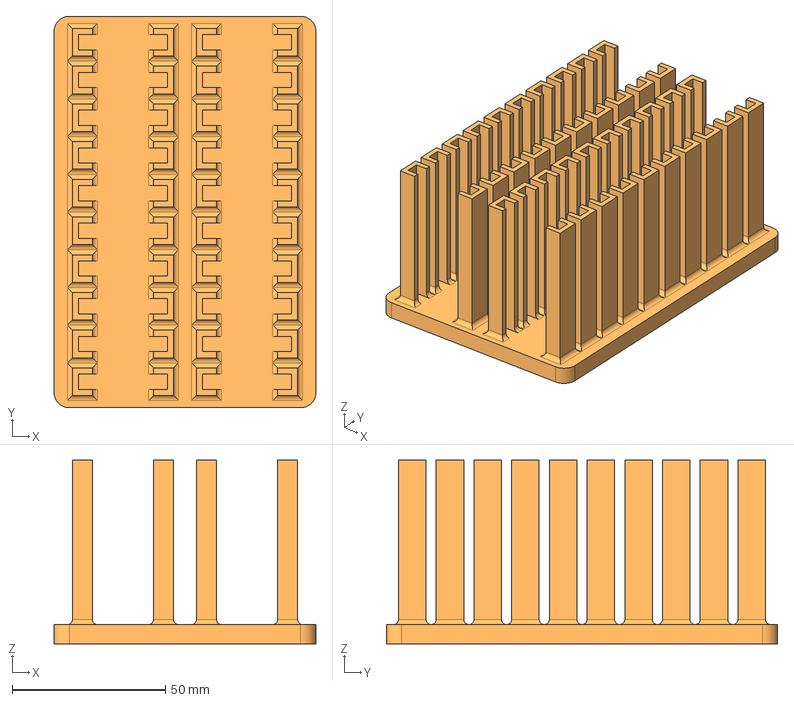
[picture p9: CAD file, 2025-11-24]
cad_models/tools/sample_holders/step_files/wet_sample_holder.step
85.5 x 127.8 x 60.0 mm

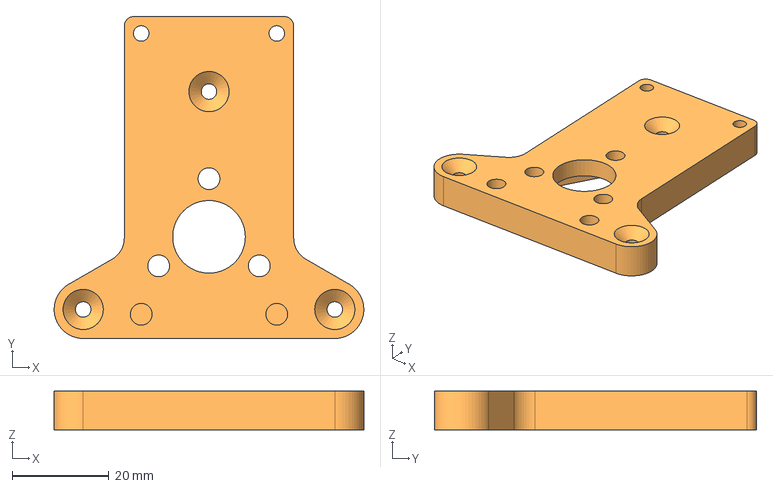
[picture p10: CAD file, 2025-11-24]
cad_models/tools/vacuum/step_files/vacuum_tool_plate.step
63.9 x 66.5 x 8.00 mm

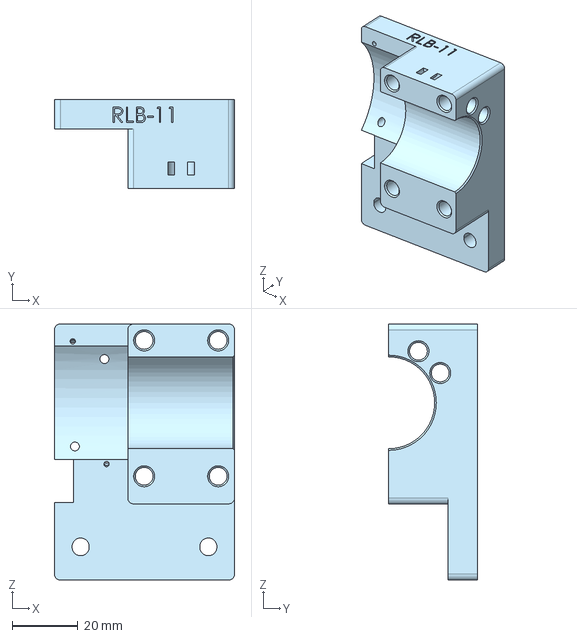
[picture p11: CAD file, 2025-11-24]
cad_models/hardware_modifications/modified_heat_insert_components/m3_heat_inserts/step_files/resin_rel_base_plate_lock_actuator_base_plate.step
54.9 x 27.0 x 78.0 mm

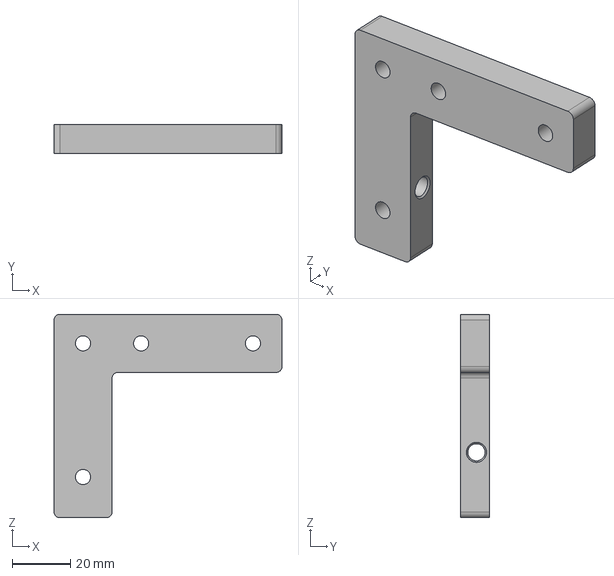
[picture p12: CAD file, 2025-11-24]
cad_models/hardware_modifications/modified_heat_insert_components/m4_heat_inserts/step_files/resin_motor_corner_bracket_spacer_left_motor_spacer.step
78.5 x 10.0 x 70.0 mm

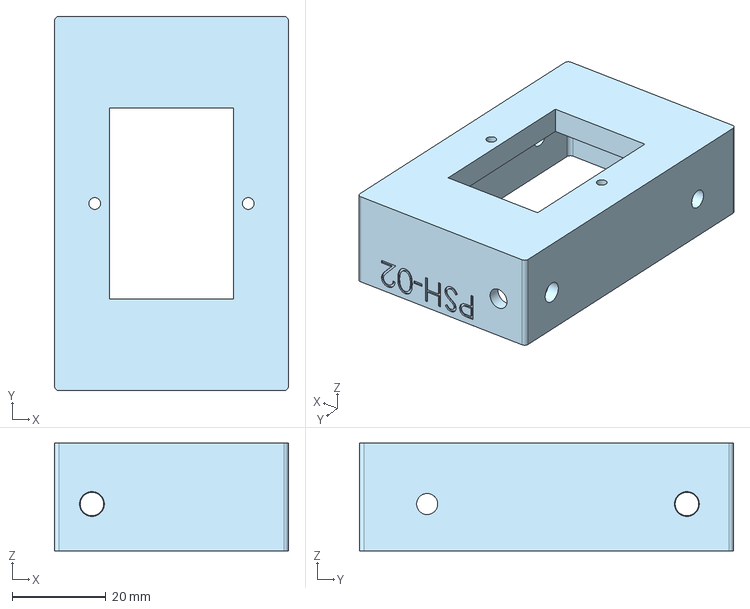
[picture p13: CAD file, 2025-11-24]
cad_models/hardware_modifications/other_modified_components/step_files/psu_socket_holder.step
50.0 x 80.0 x 23.0 mm

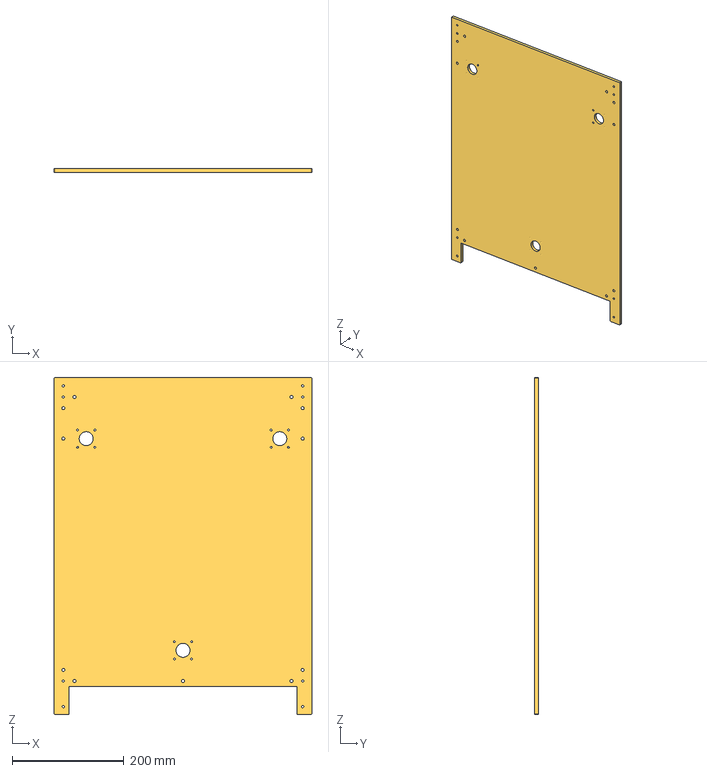
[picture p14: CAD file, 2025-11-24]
cad_models/hardware_modifications/top-bottom_plates/step_files/frame_bottom_plate.step
461.7 x 6.35 x 604.0 mm

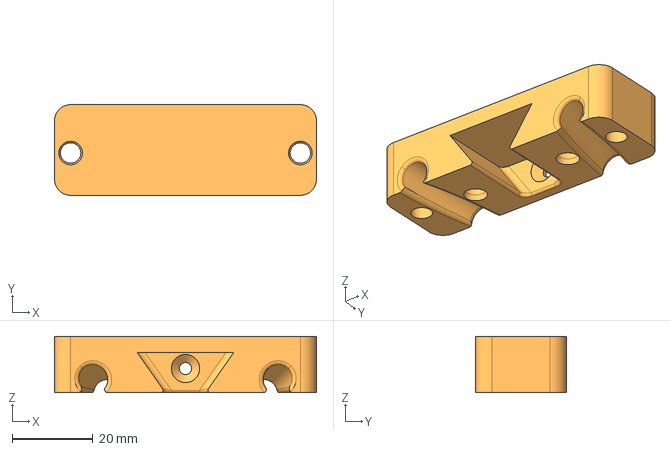
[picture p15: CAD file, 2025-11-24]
cad_models/tools/OT2_pipette/step_files/modified_pipette_tool_holder.step
65.0 x 22.5 x 14.0 mm

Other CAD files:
cad_models/hardware_modifications/modified_heat_insert_components/m3_heat_inserts/sldprt_files/fixed_pulley.sldprt
cad_models/hardware_modifications/modified_heat_insert_components/m3_heat_inserts/sldprt_files/carriage_fixed_pulley.sldprt
cad_models/tools/raspyberry_pi_cam/step_files/modified_camera_tool_plate.step
cad_models/tools/sample_holders/step_files/scintillation_vial_holder.step
cad_models/hardware_modifications/modified_heat_insert_components/m3_heat_inserts/sldprt_files/carriage_back_plate.sldprt
cad_models/hardware_modifications/modified_heat_insert_components/m3_heat_inserts/sldprt_files/carriage_center_plate.sldprt
cad_models/hardware_modifications/modified_heat_insert_components/m3_heat_inserts/sldprt_files/rel_half_pulley_floating_pulley.sldprt
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

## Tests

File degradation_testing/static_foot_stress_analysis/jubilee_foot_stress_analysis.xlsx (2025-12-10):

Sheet: Mass and Forces
System | Weight (lb) | Mass (kg) | Total Force (N) | Force per Foot (N)
Modified Jubilee | 41 | 18.597 | 182.44 | 45.61
Original Jubilee | 31.2 | 14.152 | 138.83 | 34.71

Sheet: Stress Analysis
System | Back Foot Area (mm²) | Front Foot Area (mm²) | σ_back Normal (MPa) | σ_front Normal (MPa) | σ_back Worst-Case (MPa) | σ_front Worst-Case (MPa)
Modified Jubilee | 1700 | 1200 | 0.0268 | 0.038 | 0.0537 | 0.076
Original Jubilee | 1404 | 904 | 0.0247 | 0.0384 | 0.0494 | 0.0768

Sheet: Safety Factors
System | Yield Stress (MPa) | SF Back (Normal) | SF Front (Normal) | SF Back (Worst-Case) | SF Front (Worst-Case) | Min Safety Factor
Modified Jubilee | 25 | 931.8 | 657.8 | 465.9 | 328.9 | 328.9
Original Jubilee | 25 | 1011.3 | 651.1 | 505.6 | 325.6 | 325.6

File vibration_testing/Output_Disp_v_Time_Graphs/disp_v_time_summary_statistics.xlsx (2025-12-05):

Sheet: Detailed Statistics
File Name | Accelerometer Location | RMS Displacement (mm) | Peak Displacement (mm) | Peak Time (s)
Modified Jubilee x-axis | Bed Plate | 0.804986 | 2.771859 | 10.865
 | Vertical Extrusion | 0.803846 | 2.92612 | 48.723
 | Tool Head | 0.821809 | 2.57734 | 59.705
Modified Jubilee y-axis | Bed Plate | 0.784556 | 3.231295 | 80.993
 | Vertical Extrusion | 0.713841 | 3.135374 | 0.077
 | Tool Head | 0.664444 | 2.378165 | 77.349
Modified Jubilee z-axis | Bed Plate | 0.763109 | 2.671094 | 91.982
 | Vertical Extrusion | 0.743739 | 2.561169 | 38.589
 | Tool Head | 0.74106 | 2.706725 | 13.356
Original Jubilee x-axis | Bed Plate | 0.25087 | 1.693254 | 74.185
 | Vertical Extrusion | 0.087867 | 1.32862 | 51.721
 | Tool Head | 0.248999 | 1.82956 | 76.1
Original Jubilee y-axis | Bed Plate | 0.123313 | 1.585039 | 52.014
 | Vertical Extrusion | 0.059631 | 0.756677 | 29.476
 | Tool Head | 0.137621 | 1.451705 | 51.987
Original Jubilee z-axis | Bed Plate | 0.062096 | 0.803481 | 6.31
 | Vertical Extrusion | 0.059061 | 0.796025 | 47.402
 | Tool Head | 0.06039 | 0.787401 | 68.701
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

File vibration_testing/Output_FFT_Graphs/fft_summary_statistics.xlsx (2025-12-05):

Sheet: Detailed FFT Statistics
File Name | Accelerometer Location | Peak Number | Frequency (Hz) | Magnitude (m/s²)
Modified Jubilee x-axis | Bed Plate | 1 | 4.81 | 0.079861
 |  | 2 | 6.48 | 0.084077
 |  | 3 | 8.4 | 0.074564
 | Vertical Extrusion | 1 | 3.75 | 0.056794
 |  | 2 | 5.22 | 0.060306
 |  | 3 | 9.69 | 0.058068
 | Tool Head | 1 | 6.83 | 0.063774
 |  | 2 | 26.69 | 0.055719
 |  | 3 | 41.09 | 0.061303
Modified Jubilee y-axis | Bed Plate | 1 | 7.12 | 0.069499
 |  | 2 | 29.38 | 0.076856
 |  | 3 | 43.86 | 0.067986
 | Vertical Extrusion | 1 | 41.31 | 0.085767
 |  | 2 | 41.67 | 0.076024
 |  | 3 | 48.29 | 0.078442
 | Tool Head | 1 | 1.39 | 0.074285
 |  | 2 | 4.9 | 0.063681
 |  | 3 | 27.06 | 0.065225
Modified Jubilee z-axis | Bed Plate | 1 | 3.3 | 0.068373
 |  | 2 | 18.1 | 0.070754
 |  | 3 | 49.9 | 0.068459
 | Vertical Extrusion | 1 | 26.66 | 0.07188
 |  | 2 | 30.6 | 0.071248
 |  | 3 | 32.67 | 0.066921
 | Tool Head | 1 | 9.17 | 0.067214
 |  | 2 | 15.27 | 0.076588
 |  | 3 | 31.18 | 0.084524
Original Jubilee x-axis | Bed Plate | 1 | 4.89 | 0.070779
 |  | 2 | 25.37 | 0.069879
 |  | 3 | 30.36 | 0.072277
 | Vertical Extrusion | 1 | 1.2 | 0.027263
 |  | 2 | 1.57 | 0.027419
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

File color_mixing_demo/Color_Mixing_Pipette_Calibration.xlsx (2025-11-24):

Step Size [mm] | Measurement 1 [μl] | Measurement 2 [μl] | Measurement 3 [μl] | Average | μl/mm | Average μl/mm
230 | 273 | 272 | 272 | 272.3333333 | 1.184057971 | 1.158695652
115 | 132 | 130 | 129 | 130.3333333 | 1.133333333

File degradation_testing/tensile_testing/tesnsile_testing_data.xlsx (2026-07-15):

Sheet: Summary
PLA
 | File | Ultimate Tensile Strength (UTS) [MPa] | Tensile Strain at UTS | Young's Modulus (E) [MPa]
IPA | PLA-IPA-1.csv | 25.59600629 | 0.39 | 7.2
 | PLA-IPA-2.csv | 24.83789308 | 0.30 | -3.0
 | PLA-IPA-3.csv | 29.5723978 | 0.27 | -1.5
 | PLA-IPA-4.csv | 15.49314465 | 0.35 | 0.76
 | PLA-IPA-5.csv | 27.83899371 | 0.25 | -1.3
 | Average | 24.66768711 | 0.31 | 0.44
 | Standard Deviation | 5.5 | 0.056 | 4.0
 | Standard Deviation of the Mean | 2.4 | 0.025 | 1.8
Water | PLA-W-1.csv | 45.41130503 | 0.20 | 4.5
 | PLA-W-2.csv | 44.67586478 | 0.20 | 3.2
 | PLA-W-3.csv | 44.48430818 | 0.20 | 1.6
 | PLA-W-4.csv | 45.51851415 | 0.22 | 3.9
 | PLA-W-5.csv | 40.84617925 | 0.25 | 1.3
 | Average | 44.18723428 | 0.22 | 2.9
 | Standard Deviation | 1.9 | 0.023 | 1.4
 | Standard Deviation of the Mean | 0.86 | 0.010 | 0.64
Acetone | PLA-A-1.csv | 44.10050314 | 0.20 | 1.6
 | PLA-A-2.csv | 44.63481918 | 0.17 | 2.7
 | PLA-A-3.csv | 46.24327044 | 0.20 | 2.7
 | PLA-A-4.csv | 42.44013365 | 0.22 | 2.4
 | PLA-A-5.csv | 45.72988208 | 0.21 | 4.7
 | Average | 44.6297217 | 0.20 | 2.8
 | Standard Deviation | 1.5 | 0.020 | 1.2
 | Standard Deviation of the Mean | 0.67 | 0.0090 | 0.52
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

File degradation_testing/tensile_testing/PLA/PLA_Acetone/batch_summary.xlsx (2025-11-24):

File | Tensile Strength (MPa) | Tensile Strain | Young's Modulus (MPa)
PLA-A-1.csv | 44.10050314 | 0.2036395013 | 1.568819356
PLA-A-2.csv | 44.63481918 | 0.1695275591 | 2.652379733
PLA-A-3.csv | 46.24327044 | 0.1957742782 | 2.663094079
PLA-A-4.csv | 42.44013365 | 0.2226290026 | 2.432395615
PLA-A-5.csv | 45.72988208 | 0.2115485564 | 4.71752097
Average | 44.6297217 | 0.2006237795 | 2.806841951

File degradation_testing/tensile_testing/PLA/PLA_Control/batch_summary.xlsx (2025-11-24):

File | Tensile Strength (MPa) | Tensile Strain | Young's Modulus (MPa)
P-run-1.csv | 42.26562893 | 0.2114610236 | 5.023597708
P-run-2.csv | 44.88023585 | 0.2161023622 | 2.651337938
P-run-3.csv | 43.31245283 | 0.2351531496 | 5.141330712
P-run-4.csv | 42.03745283 | 0.2206912073 | 0.06346736223
P-run-5.csv | 41.60454403 | 0.1957654856 | 5.162505212
Average | 42.82006289 | 0.2158346457 | 3.608447787

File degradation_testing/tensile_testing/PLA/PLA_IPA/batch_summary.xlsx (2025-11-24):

File | Tensile Strength (MPa) | Tensile Strain | Young's Modulus (MPa)
PLA-IPA-1.csv | 25.59600629 | 0.3912686352 | 7.205855549
PLA-IPA-2.csv | 24.83789308 | 0.3007217848 | -3.006386288
PLA-IPA-3.csv | 29.5723978 | 0.2692257218 | -1.461305554
PLA-IPA-4.csv | 15.49314465 | 0.3453455381 | 0.7607014152
PLA-IPA-5.csv | 27.83899371 | 0.2547988189 | -1.322358967
Average | 24.66768711 | 0.3122720997 | 0.4353012308

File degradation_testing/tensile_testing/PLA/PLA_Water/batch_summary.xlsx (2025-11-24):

File | Tensile Strength (MPa) | Tensile Strain | Young's Modulus (MPa)
PLA-W-1.csv | 45.41130503 | 0.2009885827 | 4.537759673
PLA-W-2.csv | 44.67586478 | 0.20297021 | 3.224631409
PLA-W-3.csv | 44.48430818 | 0.2035958005 | 1.599416854
PLA-W-4.csv | 45.51851415 | 0.2239807087 | 3.87422893
PLA-W-5.csv | 40.84617925 | 0.2548250656 | 1.256585764
Average | 44.18723428 | 0.2172720735 | 2.898524526

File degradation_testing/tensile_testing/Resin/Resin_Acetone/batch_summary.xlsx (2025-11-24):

File | Tensile Strength (MPa) | Tensile Strain | Young's Modulus (MPa)
Resin_A_1.csv | 65.8646934 | 0.4234164042 | 3.054814016
Resin_A_2a.csv | 63.97477987 | 0.4306692913 | 5.155019165
Resin_A_3.csv | 64.03787736 | 0.4057217848 | 4.991450489
Resin_A_4.csv | 62.76569182 | 0.3965748031 | 4.877116228
Resin_A_5.csv | 63.36017296 | 0.3736439633 | 6.579803367
Average | 60.21346829 | 0.3908646763 | 5.07863102

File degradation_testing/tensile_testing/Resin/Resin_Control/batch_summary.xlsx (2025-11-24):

File | Tensile Strength (MPa) | Tensile Strain | Young's Modulus (MPa)
R-run-1.csv | 65.92360849 | 0.3059754593 | 3.69753477
R-run-2.csv | 66.00014937 | 0.4345888451 | 2.459310736
R-run-3.csv | 61.51080975 | 0.2777996063 | 4.405890365
R-run-4.csv | 62.87359277 | 0.3316535433 | 3.678961334
R-run-5.csv | 64.14765723 | 0.3348950131 | 3.614817324
Average | 64.09116352 | 0.3369824934 | 3.571302906

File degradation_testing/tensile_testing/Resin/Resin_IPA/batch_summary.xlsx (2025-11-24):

File | Tensile Strength (MPa) | Tensile Strain | Young's Modulus (MPa)
Resin_IPA_1.csv | 34.37269654 | 0.2902230971 | 5.03241649
Resin_IPA_2.csv | 36.16302673 | 0.367642126 | 4.642463032
Resin_IPA_3.csv | 34.16839623 | 0.3197681102 | 2.982468128
Resin_IPA_4.csv | 30.3596934 | 0.2967935696 | 2.854582538
Resin_IPA_5.csv | 26.65608491 | 0.1544225722 | 4.86651401
Average | 32.34397956 | 0.285769895 | 4.07568884

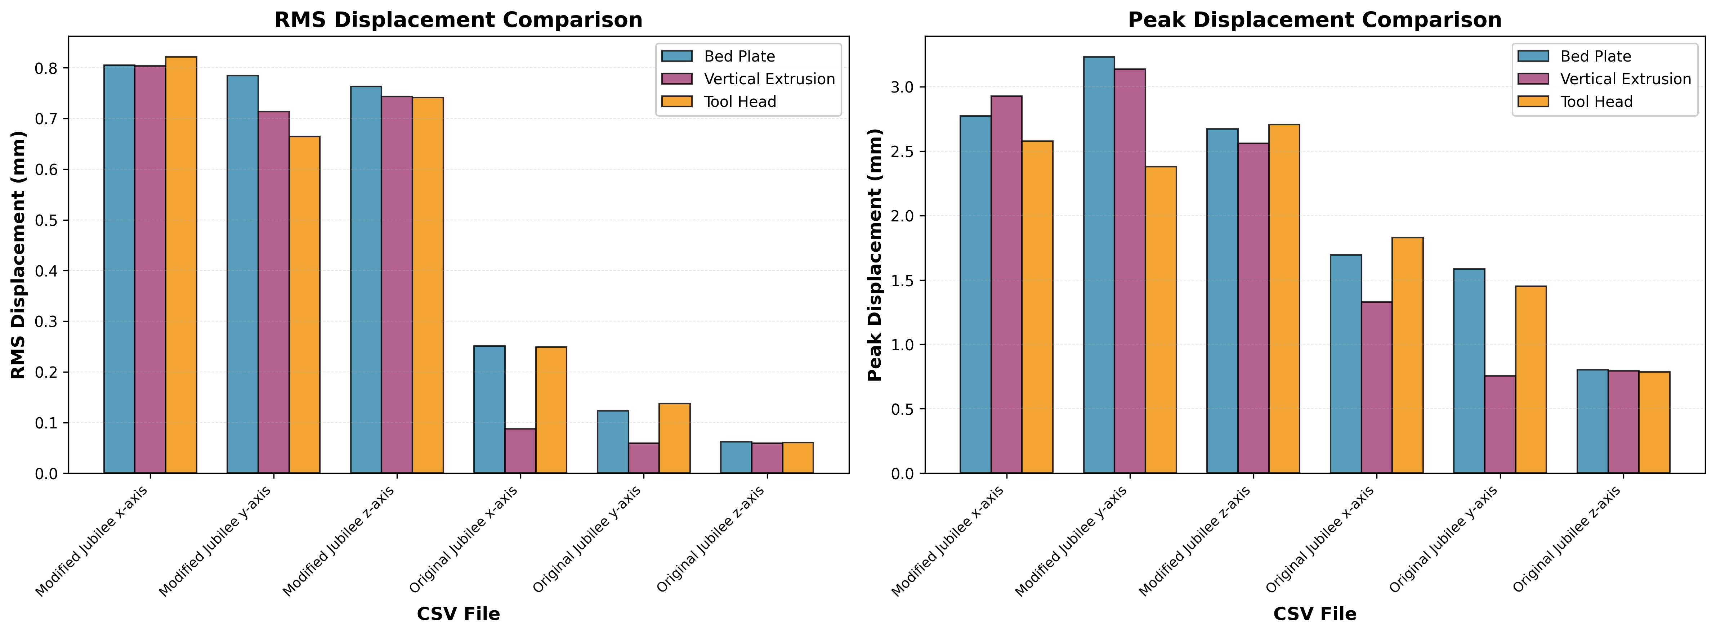
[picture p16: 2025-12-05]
vibration_testing/Output_Disp_v_Time_Graphs/disp_v_time_summary.png

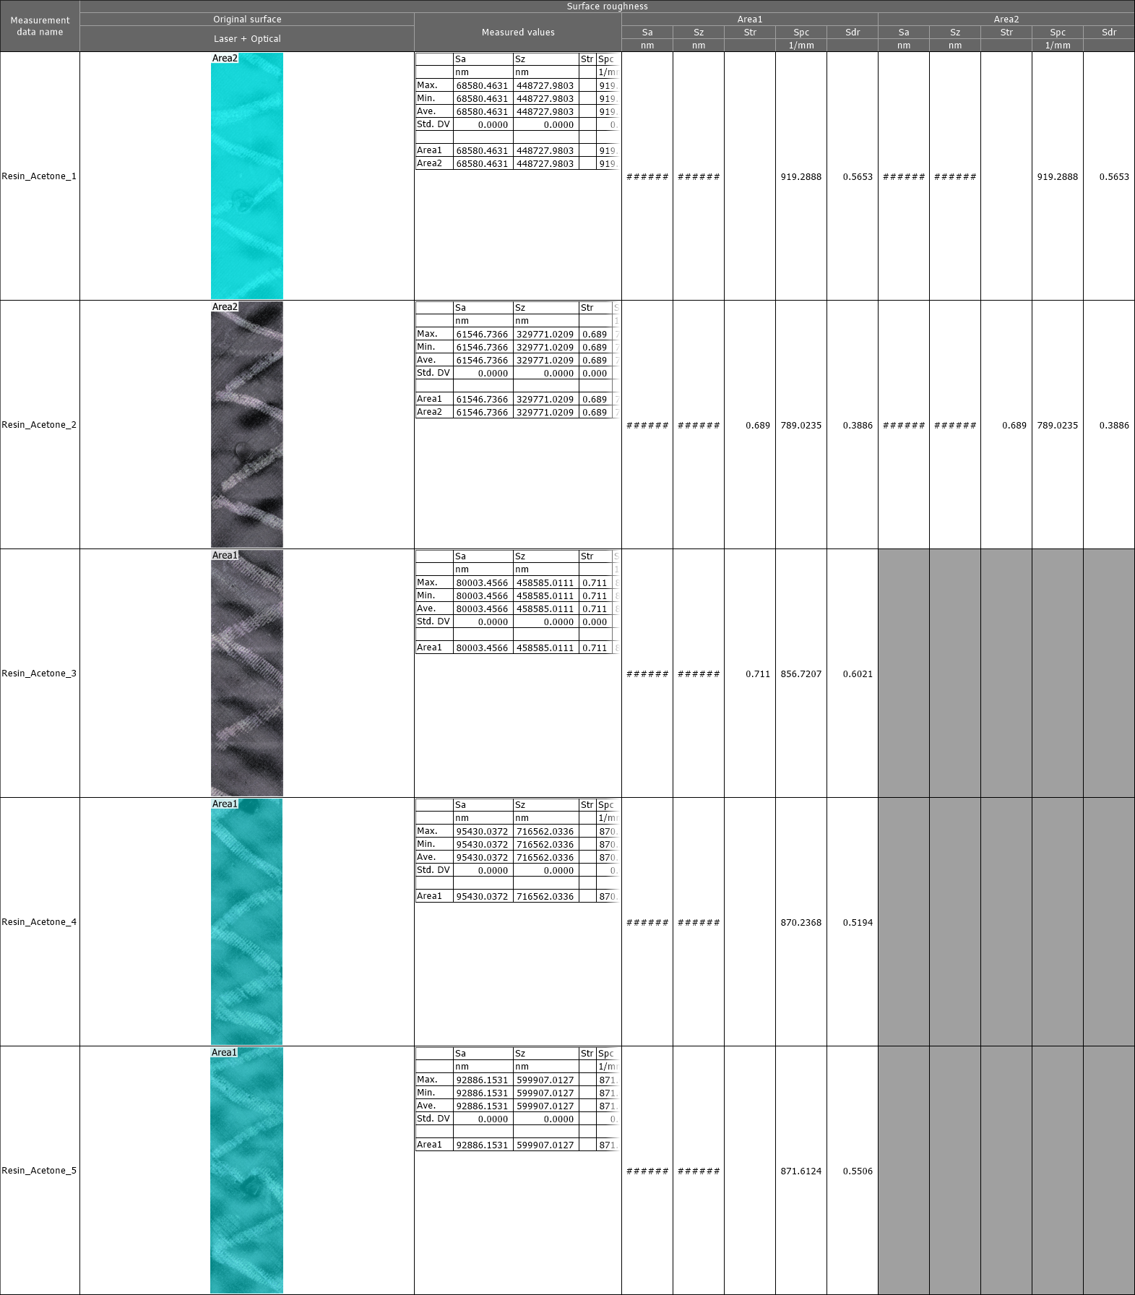
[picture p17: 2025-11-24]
degradation_testing/keyence_analysis/Resin_Acetone_Results_Surface roughness.png

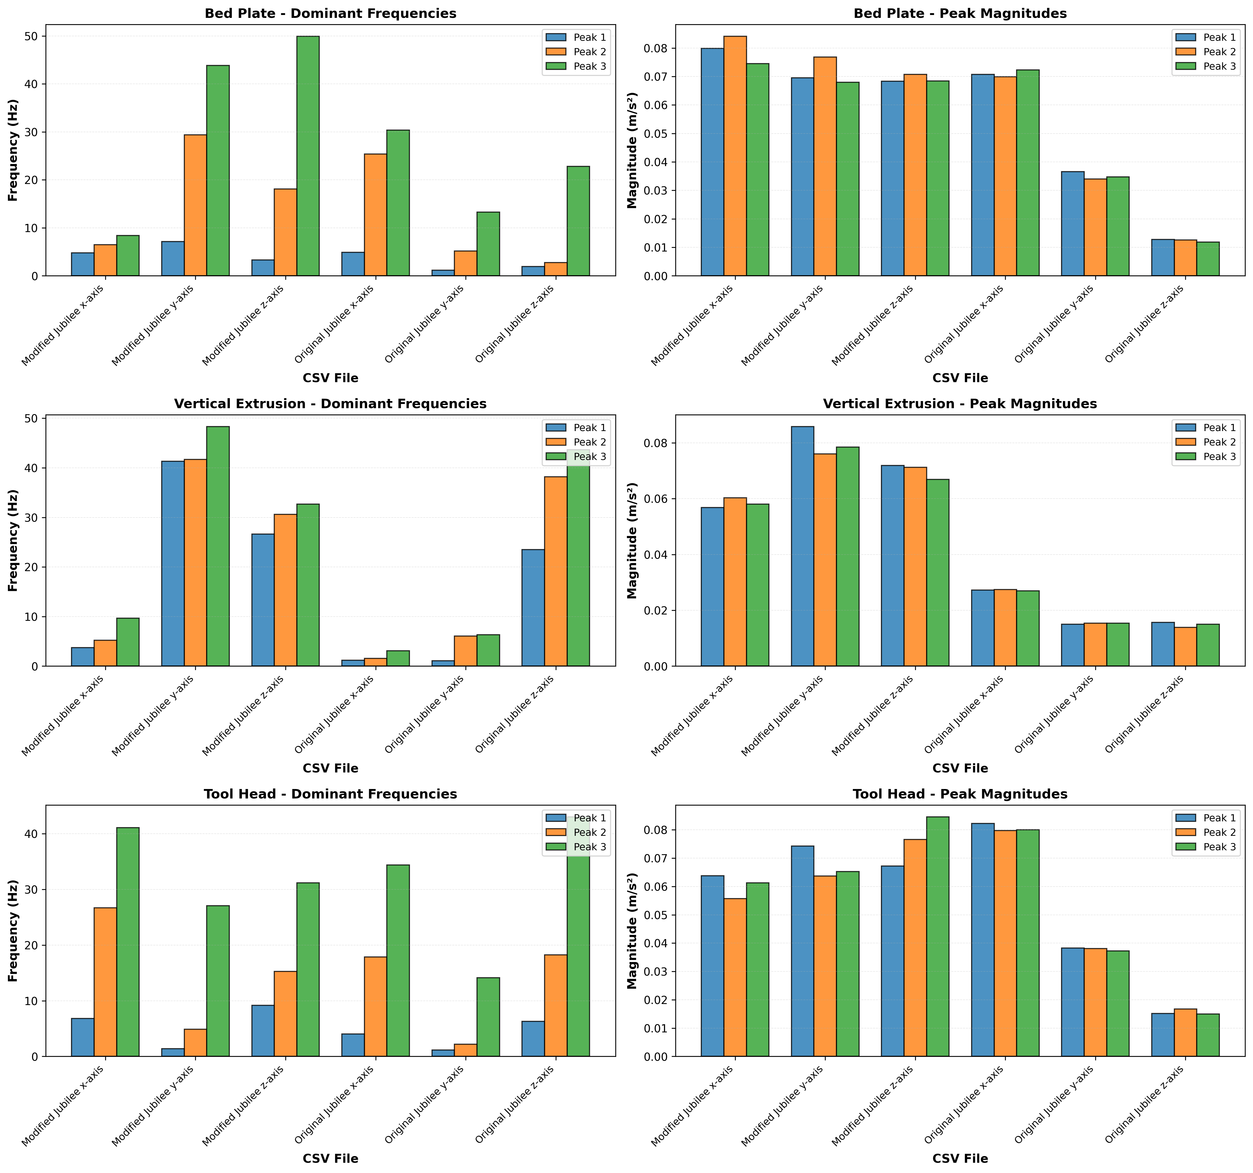
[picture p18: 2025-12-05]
vibration_testing/Output_FFT_Graphs/fft_summary.png

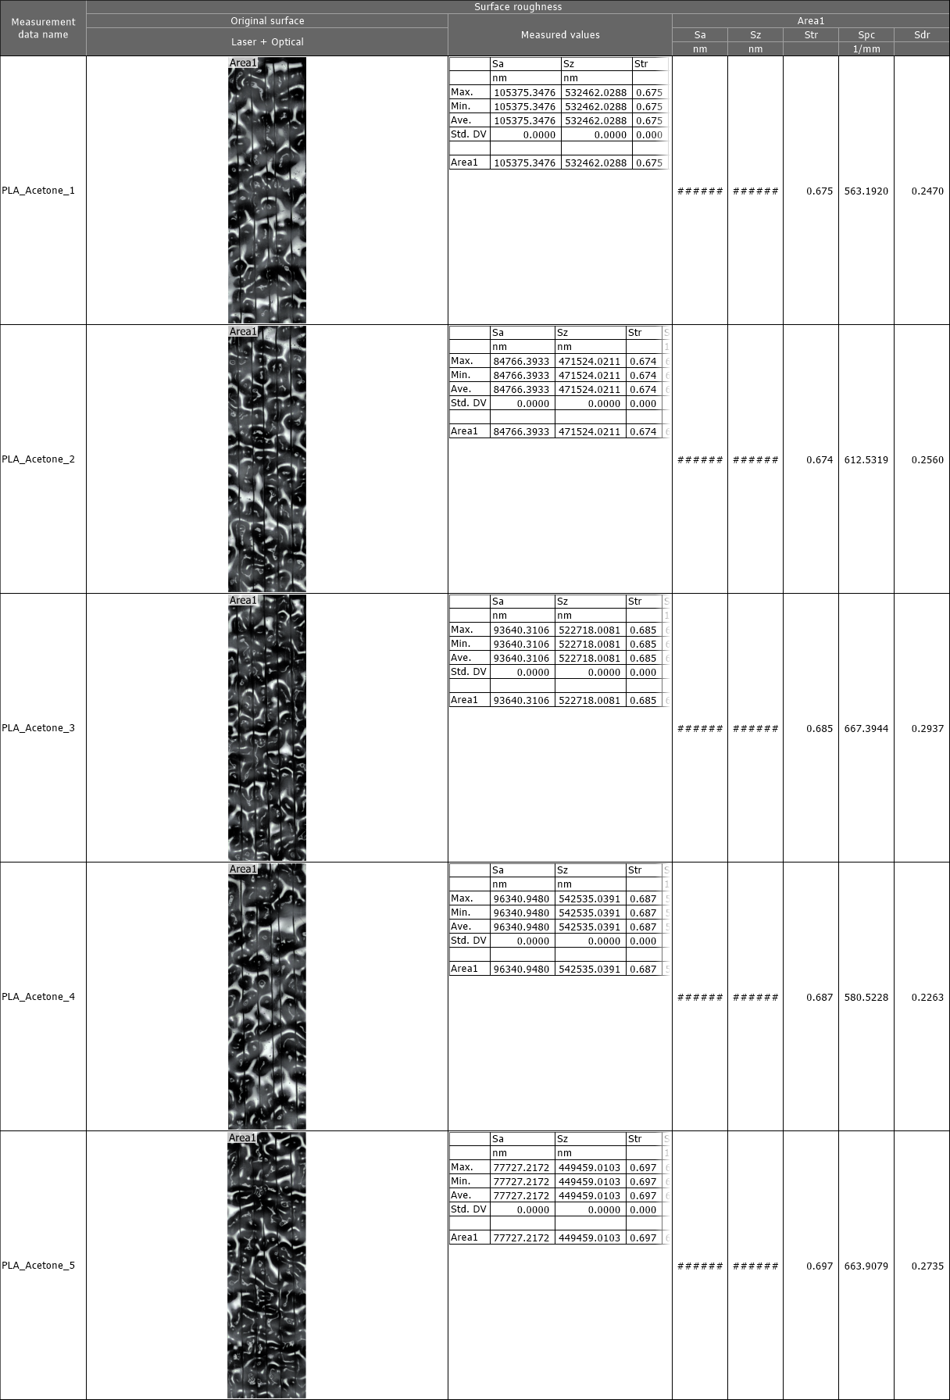
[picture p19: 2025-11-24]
degradation_testing/keyence_analysis/PLA_Acetone_Results_Surface roughness.png

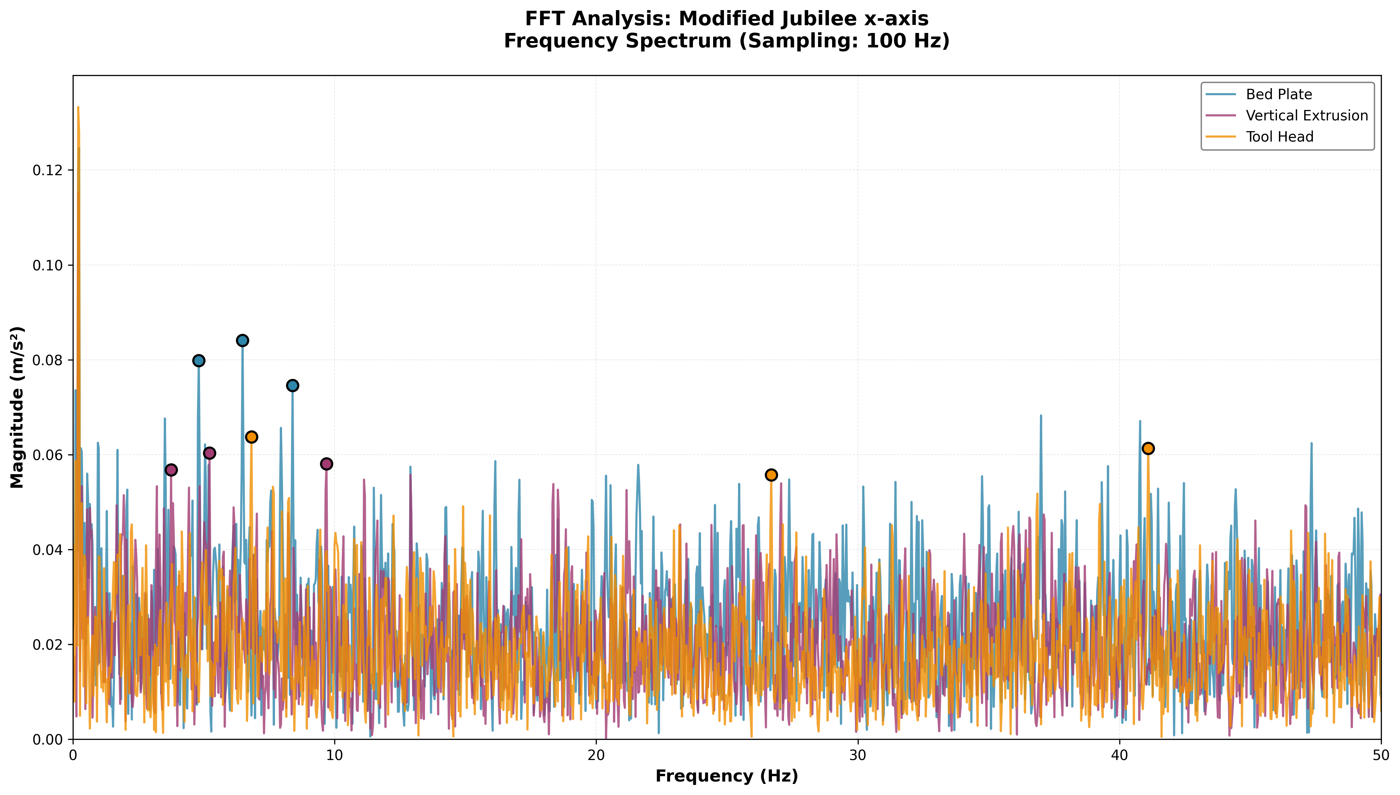
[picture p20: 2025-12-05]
vibration_testing/Output_FFT_Graphs/Modified Jubilee x-axis_fft.png

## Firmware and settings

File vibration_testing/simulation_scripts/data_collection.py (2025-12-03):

import machine
import utime
from machine import Pin, I2C
import ustruct

class PCA9548A:
    """I2C Multiplexer for managing multiple devices with same address"""
    def __init__(self, i2c, addr=0x70):
        self.i2c = i2c
        self.addr = addr
        self.current_channel = None
        
    def select_channel(self, channel):
        """Select a channel (0-7) on the multiplexer"""
        if channel < 0 or channel > 7:
            raise ValueError("Channel must be 0-7")
        
        # Write channel selection byte (bit pattern)
        channel_byte = 1 << channel
        self.i2c.writeto(self.addr, bytes([channel_byte]))
        self.current_channel = channel
        utime.sleep_ms(1)  # Small delay for channel switching
        
    def disable_all_channels(self):
        """Disable all channels"""
        self.i2c.writeto(self.addr, bytes([0x00]))
        self.current_channel = None
        utime.sleep_ms(1)

class MPU6050_Direct:
    """MPU6050 class for direct I2C connection (no PCA multiplexer)"""
    def __init__(self, i2c, addr=0x68, name="MPU"):
        self.i2c = i2c
        self.addr = addr
        self.name = name
        
        # Calibration offsets
        self.offset_x = 0.0
        self.offset_y = 0.0
        self.offset_z = 0.0
        
        # Wake up the MPU6050
        try:
            self.i2c.writeto_mem(self.addr, 0x6B, b'\x00')
            utime.sleep_ms(100)
            print(f"{self.name} direct connection (0x{self.addr:02X}) initialized successfully")
        except Exception as e:
            print(f"Failed to initialize {self.name} at 0x{self.addr:02X}: {e}")
            raise
    
    def read_raw_data(self, addr):
        data = self.i2c.readfrom_mem(self.addr, addr, 2)
        value = ustruct.unpack('>h', data)[0]
        return value
    
    def get_raw_acceleration(self):
        """Get raw acceleration without calibration"""
        accel_x_raw = self.read_raw_data(0x3B)
        accel_y_raw = self.read_raw_data(0x3D)
        accel_z_raw = self.read_raw_data(0x3F)
        
        # Convert to g's
        accel_x = accel_x_raw / 16384.0
        accel_y = accel_y_raw / 16384.0
        accel_z = accel_z_raw / 16384.0
        
        return accel_x, accel_y, accel_z
    
    def get_acceleration(self):
        """Get calibrated acceleration"""
        accel_x, accel_y, accel_z = self.get_raw_acceleration()
        
        # Apply calibration offsets
        accel_x -= self.offset_x
        accel_y -= self.offset_y
        accel_z -= self.offset_z
        
        return accel_x, accel_y, accel_z
    
    def calibrate(self, samples=200):
        """Calibrate accelerometer - sensor must be level and stationary"""
        print(f"Calibrating {self.name}... Keep sensor level and still for {samples//10} seconds")
        
        sum_x, sum_y, sum_z = 0, 0, 0
        
        for i in range(samples):
            try:
                accel_x, accel_y, accel_z = self.get_raw_acceleration()
                sum_x += accel_x
                sum_y += accel_y
                sum_z += accel_z
                
                if i % 20 == 0:  # Progress indicator
                    print(".", end="")
                
                utime.sleep_ms(10)
            except Exception as e:
                print(f"\nError during calibration of {self.name}: {e}")
                return None, None, None
        
        # Calculate average readings
        avg_x = sum_x / samples
        avg_y = sum_y / samples
        avg_z = sum_z / samples
        
        # Set offsets (Z should read +1g when level, X and Y should read 0g)
        self.offset_x = avg_x
        self.offset_y = avg_y
        self.offset_z = avg_z - 1.0  # Subtract 1g for gravity
        
        print(f"\n{self.name} calibration complete!")
        print(f"Offsets: X={self.offset_x:.4f}, Y={self.offset_y:.4f}, Z={self.offset_z:.4f}")

class MPU6050_PCA:
    """MPU6050 class for connection through PCA9548A multiplexer"""
    def __init__(self, i2c, pca, channel, addr=0x68, name="MPU"):
        self.i2c = i2c
        self.pca = pca
        self.channel = channel
        self.addr = addr
        self.name = name
        
        # Calibration offsets
        self.offset_x = 0.0
        self.offset_y = 0.0
        self.offset_z = 0.0
        
        # Initialize the sensor
        self._select_and_init()
        
    def _select_and_init(self):
        """Select PCA channel and initialize MPU6050"""
        try:
            self.pca.select_channel(self.channel)
            utime.sleep_ms(10)
            # Wake up the MPU6050
            self.i2c.writeto_mem(self.addr, 0x6B, b'\x00')
            utime.sleep_ms(100)
            print(f"{self.name} on PCA channel {self.channel} (0x{self.addr:02X}) initialized successfully")
        except Exception as e:
            print(f"Failed to initialize {self.name} on channel {self.channel}: {e}")
            raise
    
    def read_raw_data(self, addr):
        """Read raw data from sensor (with PCA channel selection)"""
        self.pca.select_channel(self.channel)
        utime.sleep_ms(2)  # Small delay for channel switching
        data = self.i2c.readfrom_mem(self.addr, addr, 2)
        value = ustruct.unpack('>h', data)[0]
        return value
    
    def get_raw_acceleration(self):
        """Get raw acceleration without calibration"""
        accel_x_raw = self.read_raw_data(0x3B)
        accel_y_raw = self.read_raw_data(0x3D)
        accel_z_raw = self.read_raw_data(0x3F)
        
        # Convert to g's
        accel_x = accel_x_raw / 16384.0
        accel_y = accel_y_raw / 16384.0
        accel_z = accel_z_raw / 16384.0
        
        return accel_x, accel_y, accel_z
    
    def get_acceleration(self):
        """Get calibrated acceleration"""
        accel_x, accel_y, accel_z = self.get_raw_acceleration()
        
        # Apply calibration offsets
        accel_x -= self.offset_x
        accel_y -= self.offset_y
        accel_z -= self.offset_z
        
        return accel_x, accel_y, accel_z
    
    def calibrate(self, samples=200):
        """Calibrate accelerometer - sensor must be level and stationary"""
        print(f"Calibrating {self.name} on channel {self.channel}... Keep sensor level and still for {samples//10} seconds")
        
        sum_x, sum_y, sum_z = 0, 0, 0
        
        for i in range(samples):
            try:
                accel_x, accel_y, accel_z = self.get_raw_acceleration()
                sum_x += accel_x
                sum_y += accel_y
                sum_z += accel_z
                
                if i % 20 == 0:  # Progress indicator
                    print(".", end="")
                
                utime.sleep_ms(10)
            except Exception as e:
                print(f"\nError during calibration of {self.name}: {e}")
                return None, None, None
        
        # Calculate average readings
        avg_x = sum_x / samples
        avg_y = sum_y / samples
        avg_z = sum_z / samples
        
        # Set offsets (Z should read +1g when level, X and Y should read 0g)
        self.offset_x = avg_x
        self.offset_y = avg_y
        self.offset_z = avg_z - 1.0  # Subtract 1g for gravity
        
        print(f"\n{self.name} calibration complete!")
        print(f"Offsets: X={self.offset_x:.4f}, Y={self.offset_y:.4f}, Z={self.offset_z:.4f}")
        return self.offset_x, self.offset_y, self.offset_z

def wait_for_sensors_to_settle(sensors, settling_time_sec=5, stability_threshold=0.05, check_samples=20):
    """
    Wait for all sensors to settle before starting data recording.
    
    Args:
        sensors: List of sensor objects
        settling_time_sec: Minimum time to wait for initial settling
        stability_threshold: Maximum standard deviation allowed for stability (in g's)
        check_samples: Number of samples to check for stability
    
    Returns:
        True if all sensors settled successfully
    """
    print(f"\nWaiting for sensors to settle...")
    print(f"Initial settling period: {settling_time_sec} seconds")
    
    # Initial settling time - let sensors warm up and stabilize
    for i in range(settling_time_sec):
        print(f"Initial settling: {i+1}/{settling_time_sec} seconds", end="\r")
        utime.sleep(1)
    
    print("\nChecking sensor stability...")
    
    max_attempts = 10  # Maximum number of stability check attempts
    attempt = 0
    
    while attempt < max_attempts:
        attempt += 1
        print(f"Stability check attempt {attempt}/{max_attempts}")
        
        all_stable = True
        
        for sensor in sensors:
            # Collect samples for stability analysis
            readings = []
            print(f"  Checking {sensor.name}...", end="")
            
            try:
                for _ in range(check_samples):
                    accel_x, accel_y, accel_z = sensor.get_acceleration()
                    magnitude = (accel_x**2 + accel_y**2 + accel_z**2)**0.5
                    readings.append((accel_x, accel_y, accel_z, magnitude))
                    utime.sleep_ms(50)  # 20Hz sampling for stability check
                
                # Calculate standard deviations for each axis and magnitude
                if readings:
                    x_vals = [r[0] for r in readings]
                    y_vals = [r[1] for r in readings]
                    z_vals = [r[2] for r in readings]
                    mag_vals = [r[3] for r in readings]
                    
                    # Calculate means
                    x_mean = sum(x_vals) / len(x_vals)
                    y_mean = sum(y_vals) / len(y_vals)
                    z_mean = sum(z_vals) / len(z_vals)
                    mag_mean = sum(mag_vals) / len(mag_vals)
                    
                    # Calculate standard deviations
                    x_std = (sum((x - x_mean)**2 for x in x_vals) / len(x_vals))**0.5
                    y_std = (sum((y - y_mean)**2 for y in y_vals) / len(y_vals))**0.5
                    z_std = (sum((z - z_mean)**2 for z in z_vals) / len(z_vals))**0.5
                    mag_std = (sum((m - mag_mean)**2 for m in mag_vals) / len(mag_vals))**0.5
                    
                    # Check if all axes are stable
                    max_std = max(x_std, y_std, z_std, mag_std)
                    
                    if max_std <= stability_threshold:
                        print(f" STABLE (max_std: {max_std:.4f})")
                    else:
                        print(f" UNSTABLE (max_std: {max_std:.4f}, threshold: {stability_threshold})")
                        all_stable = False
                else:
                    print(" ERROR: No readings collected")
                    all_stable = False
                    
            except Exception as e:
                print(f" ERROR: {e}")
                all_stable = False
        
        if all_stable:
            print("✓ All sensors are stable and ready for data collection!")
            return True
        else:
            print(f"✗ Some sensors are still settling. Waiting 2 seconds before next check...")
            utime.sleep(2)
    
    print(f"⚠ Warning: Not all sensors achieved stability after {max_attempts} attempts.")
    print("Proceeding with data collection anyway. Data quality may be affected.")
    return False

# Configuration
SAMPLE_RATE_HZ = 100
LIVE_MODE = False  # Set to False for file logging, True for live display
CALIBRATE_ON_START = True  # Set to True to calibrate before each session
LOG_DURATION_SEC = 120  # How long to record in seconds (0 = infinite until Ctrl+C)

# Settling configuration
SETTLING_TIME_SEC = 5  # Initial settling time in seconds
STABILITY_THRESHOLD = 0.05  # Maximum allowed standard deviation for stability (g's)
STABILITY_CHECK_SAMPLES = 20  # Number of samples to check for stability

# PCA9548A and sensor configuration
PCA_ADDRESS = 0x70  # Default PCA9548A address
MPU_ADDRESS = 0x68  # MPU6050 address (same for all since using PCA)

# Sensor configuration
# Direct connection (no PCA channel)
DIRECT_SENSORS = [
    {"address": 0x68, "name": "MPU_Direct"},  # Direct connection to Pi
    # Add more direct sensors with different addresses if needed
]

# PCA channel connections
PCA_SENSORS = [
    {"channel": 0, "name": "MPU_Ch0"},  # Sensor on PCA channel 0
    {"channel": 1, "name": "MPU_Ch1"},  # Sensor on PCA channel 1
    # Add more PCA sensors here if needed:
    # {"channel": 2, "name": "MPU_Ch2"},
]

def diagnose_setup(i2c, pca_addr=0x70):
    """Diagnostic function to understand the I2C setup"""
    print("=== I2C DIAGNOSTIC ===")
    
    # Scan main bus
    main_devices = i2c.scan()
    print(f"Main I2C bus devices: {[hex(addr) for addr in main_devices]}")
    
    if pca_addr in main_devices:
        print(f"PCA9548A detected at 0x{pca_addr:02X}")
        
        try:
            # Initialize PCA
            pca = PCA9548A(i2c, pca_addr)
            
            # Test each channel individually
            print("Testing individual PCA channels:")
            for ch in [0, 1]:  # Only test your configured channels
                print(f"\n--- Channel {ch} ---")
                try:
                    pca.select_channel(ch)
                    utime.sleep_ms(50)
                    devices = i2c.scan()
                    print(f"  Devices: {[hex(addr) for addr in devices]}")
                    
                    # Try to communicate with MPU6050 if found
                    if 0x68 in devices:
                        try:
                            # Test basic communication
                            who_am_i = i2c.readfrom_mem(0x68, 0x75, 1)[0]
                            print(f"  MPU6050 WHO_AM_I: 0x{who_am_i:02X} {'(OK)' if who_am_i == 0x68 else '(ERROR)'}")
                        except Exception as e:
                            print(f"  MPU6050 communication failed: {e}")
                            
                except Exception as e:
                    print(f"  Channel {ch} error: {e}")
            
            # Disable all channels and test main bus again
            print(f"\n--- All PCA channels disabled ---")
            pca.disable_all_channels()
            utime.sleep_ms(50)
            devices = i2c.scan()
            print(f"  Main bus devices: {[hex(addr) for addr in devices]}")
            
            if 0x68 in devices:
                print("  Direct MPU6050 detected on main bus!")
                try:
                    who_am_i = i2c.readfrom_mem(0x68, 0x75, 1)[0]
                    print(f"  Direct MPU6050 WHO_AM_I: 0x{who_am_i:02X} {'(OK)' if who_am_i == 0x68 else '(ERROR)'}")
                except Exception as e:
                    print(f"  Direct MPU6050 communication failed: {e}")
            else:
                print("  No direct MPU6050 on main bus")
                
        except Exception as e:
            print(f"PCA initialization failed: {e}")
    else:
        print("No PCA9548A found")
        if 0x68 in main_devices:
            print("Direct MPU6050 found on main bus")

def scan_pca_channels(i2c, pca):
    """Scan all PCA channels to see which have devices"""
    print("Scanning PCA9548A channels...")
    found_channels = []
    
    # First disable all channels to get a clean start
    pca.disable_all_channels()
    utime.sleep_ms(50)
    
    for channel in range(8):
        try:
            # Select specific channel
            pca.select_channel(channel)
            utime.sleep_ms(50)  # More time for channel switching
            
            # Scan for devices on this channel
            devices = i2c.scan()
            
            # Filter out the PCA itself and any devices that appear on main bus
            # Only count devices that are specifically on this channel
            mpu_devices = []
            for addr in devices:
                if addr != pca.addr and addr == 0x68:  # Looking specifically for MPU6050
                    mpu_devices.append(addr)
            
            if mpu_devices:
                print(f"Channel {channel}: Found MPU devices at {[hex(addr) for addr in mpu_devices]}")
                found_channels.append(channel)
            else:
                print(f"Channel {channel}: No MPU devices")
                
        except Exception as e:
            print(f"Channel {channel}: Error - {e}")
    
    # Disable all channels when done
    pca.disable_all_channels()
    utime.sleep_ms(10)
    return found_channels
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
